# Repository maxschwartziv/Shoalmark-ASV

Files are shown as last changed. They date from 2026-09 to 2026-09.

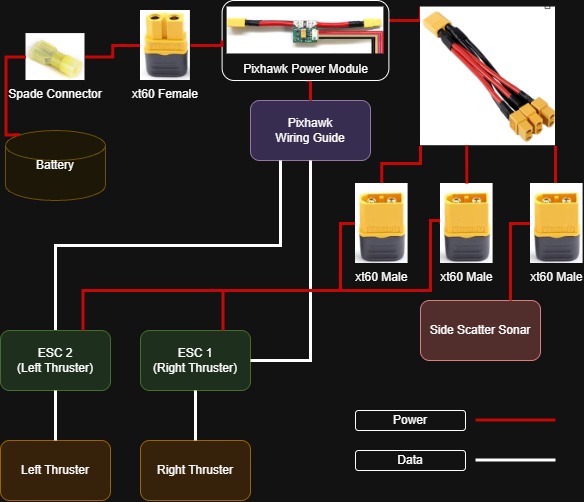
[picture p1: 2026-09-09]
Wiring Diagram Droneboat-Page-1.jpg

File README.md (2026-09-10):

**[3d print Instructions.pdf](https://github.com/user-attachments/files/32030344/3d.print.Instructions.pdf)**

pvc_ring_half_clamp 18x	

pvc_to_box_bracket 	4x

horizontal_to_vertical 1x

horizontal_to_vertical_receiver 6x

thruster_to_pvc	2x

**Parts can be printed 4 ways:**

On a creality machine with All_Parts.3mf

Place individual .3mf files

Generate/modify parts with openscad, connector_parts.scad

**[My website Build Page](https://www.droneboatfleet.com/shoalmark-asv)**

shoalmark3

shoalmark
shoalmark_thruster2

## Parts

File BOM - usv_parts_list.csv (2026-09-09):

Category | Item | Qty | Unit Price (USD) | Line Total (USD) | Source | Link | Notes
Sonar | Humminbird HELIX 7 CHIRP MEGA SI GPS G4 fish finder (transducer included) | 1 | 715 | 715 | Amazon | https://www.amazon.com/dp/B0CG6P1TD5 | ASIN B0CG6P1TD5; model 411930-1
Hull | Freein inflatable bodyboard, 40" x 21" x 4" | 1 | 80 | 80 | Amazon | https://www.amazon.com/dp/B0F1C778M2 | ASIN B0F1C778M2; hull/float platform
Frame | Charlotte Pipe 1/2" x 10 ft CPVC SDR11 pipe, plain end | 1 | 10 | 10 | Home Depot | https://www.homedepot.com/p/Charlotte-Pipe-1-2-In-X-10-Ft-CPVC-SDR11-Pipe-Plain-End-Corrosion-Resistant-for-Hot-and-Cold-Water-Distribution-CTS-12005-0600/100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 | 0.625 in OD / 0.485 in ID / 0.068 in wall
Frame | 1 in. x 2 in. x 8 ft. Furring Strip Board | 1 | 1 | 1 | Home Depot | https://www.homedepot.com/p/1-in-x-2-in-x-8-ft-Furring-Strip-Board-160954/100009348 | Actual Product Thickness (in.) 0.75 in,
Propulsion | APISQUEEN underwater thruster, CCW, 1.3 kg thrust | 1 | 65 | 65 | Amazon | https://www.amazon.com/dp/B0C74CMXR9?lv=shuf&channelId=500&plpRedirect=mhFallback&th=1 | ASIN B0C74CMXR9; 12-16V (3-4S), 8A max, 130W, 210 g
Propulsion | APISQUEEN underwater thruster, CW, 1.3 kg thrust | 1 | 65 | 65 | Amazon | https://www.amazon.com/dp/B0C74DFDYW | ASIN B0C74DFDYW; counter-rotating pair with above
Control | Pixhawk PX4 2.4.8 flight controller kit | 1 | 220 | 220 | Amazon | https://www.amazon.com/Controller-Wireless-Telemetry-Quadcopter-Multirotor/dp/B07NRMFTXL | ASIN B07NRMFTXL; incl. NEO-M8N GPS, 433 MHz telemetry pair, power module, PPM, mini OSD, safety switch, buzzer, I2C splitter
Control | HotRC transmitter + F-06A receiver set | 1 | 30 | 30 | Amazon | https://www.amazon.com/dp/B09Y8XT53X | ASIN B09Y8XT53X
Power | Akiisolo AK015 LiFePO4 battery, 12.8V 15Ah (192Wh) + charger | 1 | 40 | 40 | Amazon | https://www.amazon.com/dp/B0DLP6HWR5 | ASIN B0DLP6HWR5; 20A continuous / 30A peak
Power | XT60H connector pairs (male/female) | 1 | 12 | 12 | Amazon | https://www.amazon.com/dp/B0DPBP1N59 | ASIN B0DPBP1N59
Power | 2pcs XT60 Parallel Battery Connector Extension Y Splitter 3-Way (1Male to 3Female) | 1 | 10 | 10 | amazon | https://www.amazon.com/ATNSINC-Parallel-Connector-Extension-Splitter/dp/B0FWBMPTS4?s=industrial
Power | Duplex marine wire, 16 AWG / 2-conductor | 1 | 23 | 23 | Amazon | https://www.amazon.com/dp/B0FMK5YLB9 | ASIN B0FMK5YLB9; tinned copper, red/black
Enclosure | IP-rated enclosure with clear hinged lid | 1 | 70 | 70 | Amazon | https://www.amazon.com/dp/B09324TNT7 | ASIN B09324TNT7; electronics box
Enclosure | Cable glands / bulkhead cord grips, 6-pack | 1 | 10 | 10 | Amazon | https://www.amazon.com/dp/B0DKXHWSVX | ASIN B0DKXHWSVX; slotted, for pass-through wiring
Fasteners | Hanglife M4 heat-set threaded inserts, M4 x D6 x L6, 100 pcs | 1 | 10 | 10 | Amazon | https://www.amazon.com/dp/B0CS6XGMFD | ASIN B0CS6XGMFD; price read off the listing screenshot in the source doc
Fasteners | SVLING M4 x 12 mm socket cap screws, SS304 DIN 912, 200 pcs | 1 | 10 | 10 | Amazon | https://www.amazon.com/dp/B0GHNKNBMP | ASIN B0GHNKNBMP; includes hex key
Fasteners | TICONN 100 Pcs Nylon Spade Connector Kit, Insulated Crimp Wire Connectors | 1 | 10 | 10 | Amazon | https://www.amazon.com/TICONN-Disconnect-Connectors-Electrical-Assortment/dp/B08BZ972B5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
Adhesives & Sealing | GE Advanced Silicone 2 sealant, clear, window & door | 1 | 8 | 8 | Amazon | https://www.amazon.com/dp/B0C9VT9KD2 | ASIN B0C9VT9KD2; 100% waterproof, not paintable
Adhesives & Sealing | IXR Pro CA glue set (thin/medium/thick) + FX616 accelerator | 1 | 15 | 15 | Amazon | https://www.amazon.com/dp/B0D1DFSDMW | ASIN B0D1DFSDMW; 500 ml accelerator, applicator tips included
Ground Station | HOTWAV rugged Android 14 tablet | 1 | 209 | 209 | Amazon | https://www.amazon.com/dp/B0DK99XX8F | ASIN B0DK99XX8F; QGroundControl host
Ground Station | USB4 40 Gbps USB-C adapter | 1 | 10 | 10 | Amazon | https://www.amazon.com/dp/B0BN3LKKPQ | ASIN B0BN3LKKPQ
Printed Parts | PETG filament for printed parts (152.13 g / 49.80 m) | 1 | 4.56 | 4.56 | In-house |  | Cost, mass and 11h05m print time from the Creality slicer G-code preview in the source doc
Printed Parts | pvc_ring_half_clamp (printed) | 18 | 0 | 0 | In-house |  | connector_parts.scad; filament cost carried on the row above
Printed Parts | pvc_to_box_bracket (printed) | 4 | 0 | 0 | In-house |  | connector_parts.scad; filament cost carried above
Printed Parts | horizontal_to_vertical (printed) | 1 | 0 | 0 | In-house |  | connector_parts.scad; filament cost carried above
Printed Parts | horizontal_to_vertical_receiver (printed) | 6 | 0 | 0 | In-house |  | connector_parts.scad; filament cost carried above
Printed Parts | thruster_to_pvc (printed) | 2 | 0 | 0 | In-house |  | connector_parts.scad; filament cost carried above
 | GRAND TOTAL |  |  | 1627.56
SUBTOTALS BY CATEGORY
Sonar |  |  |  | 715
Hull |  |  |  | 80
Frame |  |  |  | 11
Propulsion |  |  |  | 130
Control |  |  |  | 250
Power |  |  |  | 85
Enclosure |  |  |  | 80
Fasteners |  |  |  | 30
Adhesives & Sealing |  |  |  | 23
Ground Station |  |  |  | 219
Printed Parts |  |  |  | 4.56

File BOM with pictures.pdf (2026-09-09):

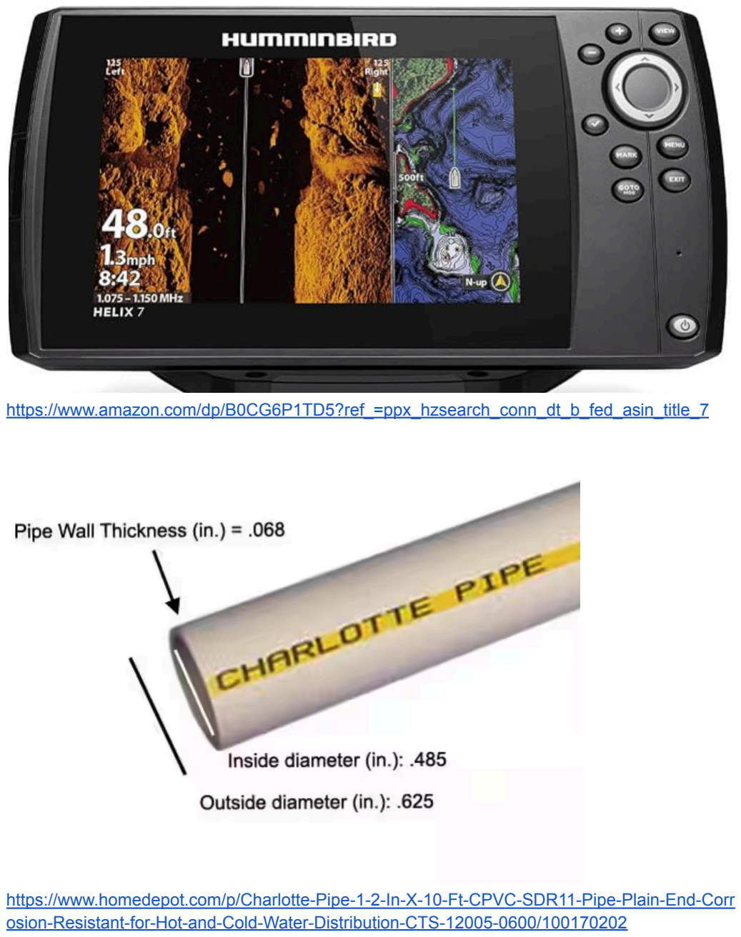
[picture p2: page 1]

https://www.amazon.com/dp/B0CG6P1TD5?ref_=ppx_hzsearch_conn_dt_b_fed_asin_title_7

https://www.homedepot.com/p/Charlotte-Pipe-1-2-In-X-10-Ft-CPVC-SDR11-Pipe-Plain-End-Corrosion-Resistant-for-Hot-and-Cold-Water-Distribution-CTS-12005-0600/100170202 (https://www.homedepot.com/p/Charlotte-Pipe-1-2-In-X-10-Ft-CPVC-SDR11-Pipe-Plain-End-Corrosion-Resistant-for-Hot-and-Cold-Water-Distribution-CTS-12005-0600/100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)

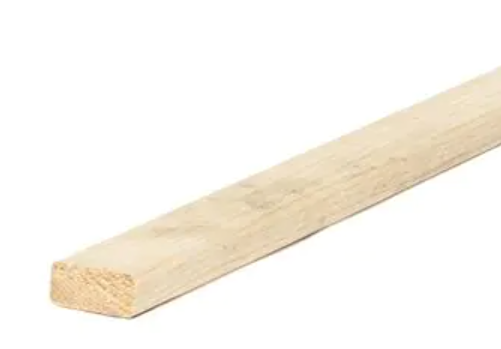
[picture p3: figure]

https://www.homedepot.com/p/1-in-x-2-in-x-8-ft-Furring-Strip-Board-160954/100009348

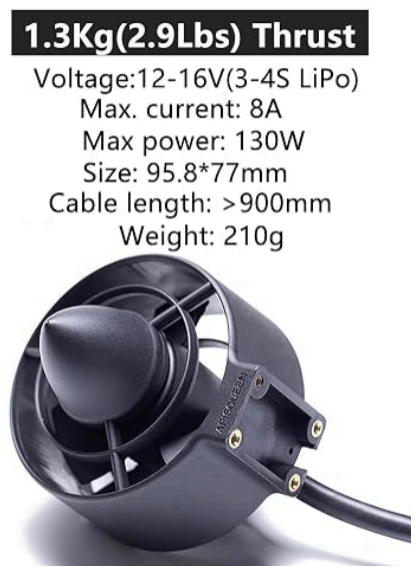
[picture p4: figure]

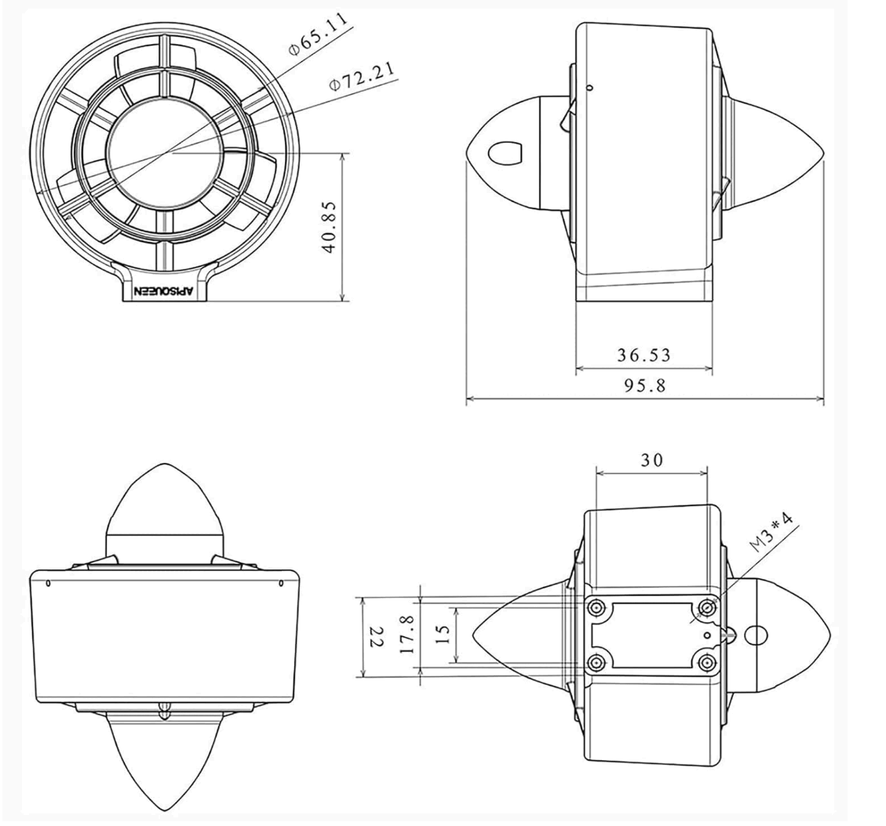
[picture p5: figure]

CCW
https://www.amazon.com/dp/B0C74CMXR9?ref_=ppx_hzsearch_conn_dt_b_fed_asin_title_2&th=1 (https://www.amazon.com/dp/B0C74CMXR9?ref_=ppx_hzsearch_conn_dt_b_fed_asin_title_2&th=1)

CW
https://www.amazon.com/dp/B0C74DFDYW?ref_=ppx_hzsearch_conn_dt_b_fed_asin_title_1&th=1 (https://www.amazon.com/dp/B0C74DFDYW?ref_=ppx_hzsearch_conn_dt_b_fed_asin_title_1&th=1)

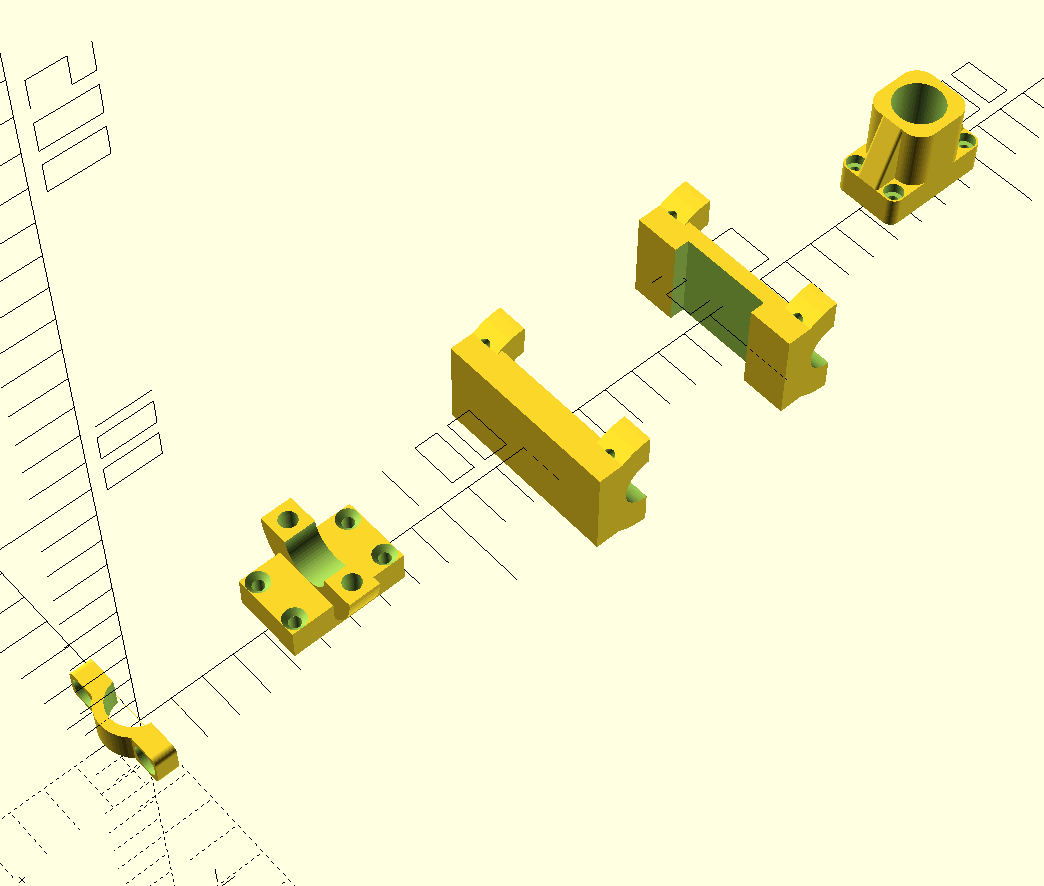
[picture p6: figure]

Connector_parts.scad

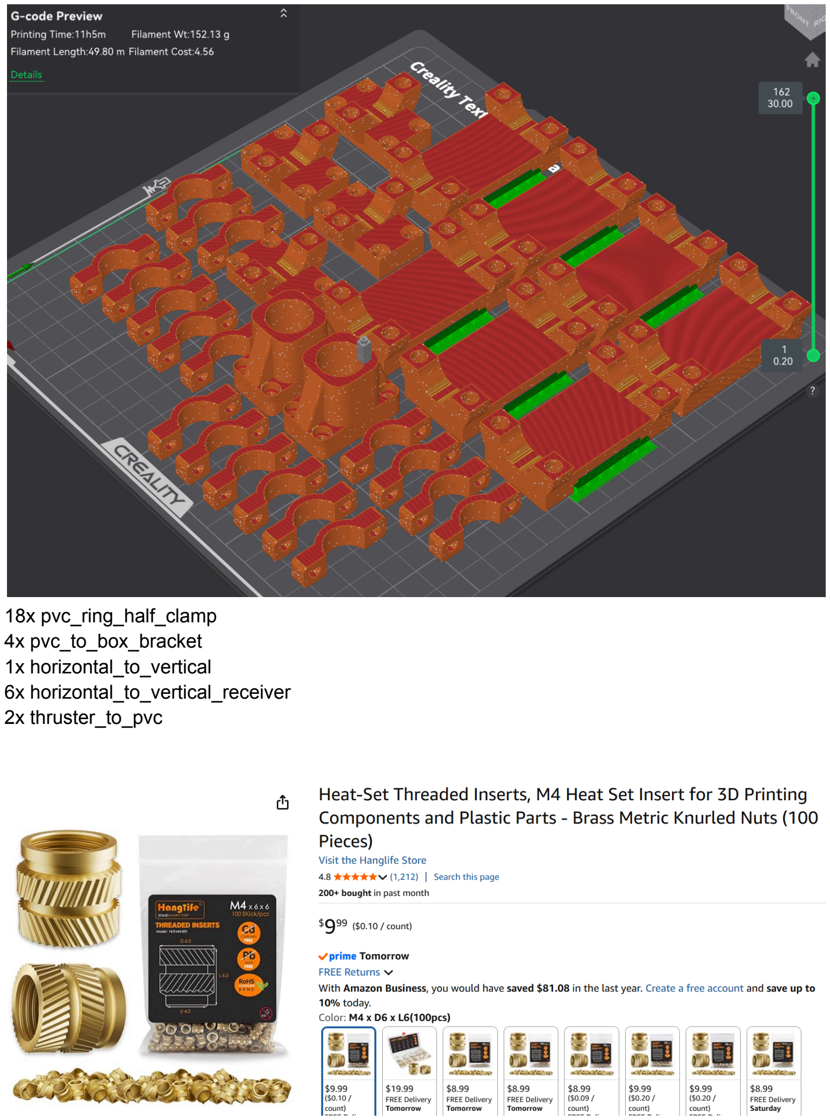
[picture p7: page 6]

18x pvc_ring_half_clamp
4x pvc_to_box_bracket
1x horizontal_to_vertical
6x horizontal_to_vertical_receiver 2x thruster_to_pvc https://www.amazon.com/dp/B0CS6XGMFD?ref_=ppx_hzsearch_conn_dt_b_fed_asin_title_1&th=1 (https://www.amazon.com/dp/B0CS6XGMFD?ref_=ppx_hzsearch_conn_dt_b_fed_asin_title_1&th=1)

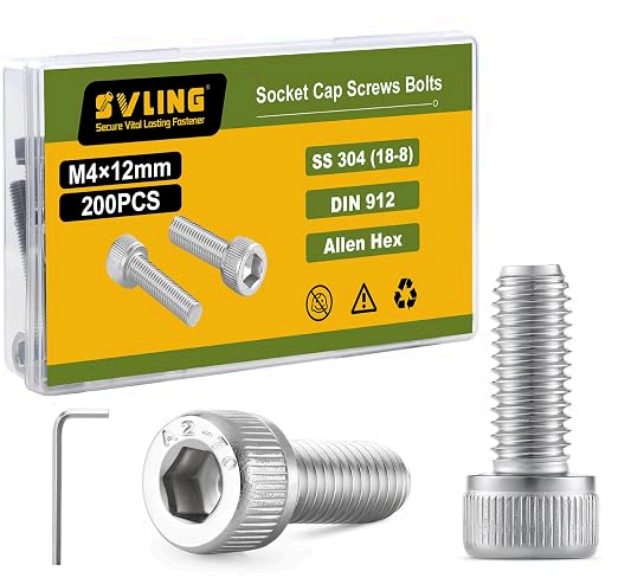
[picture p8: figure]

https://www.amazon.com/dp/B0GHNKNBMP?ref_=ppx_hzsearch_conn_dt_b_fed_asin_title_2&th=1 (https://www.amazon.com/dp/B0GHNKNBMP?ref_=ppx_hzsearch_conn_dt_b_fed_asin_title_2&th=1)

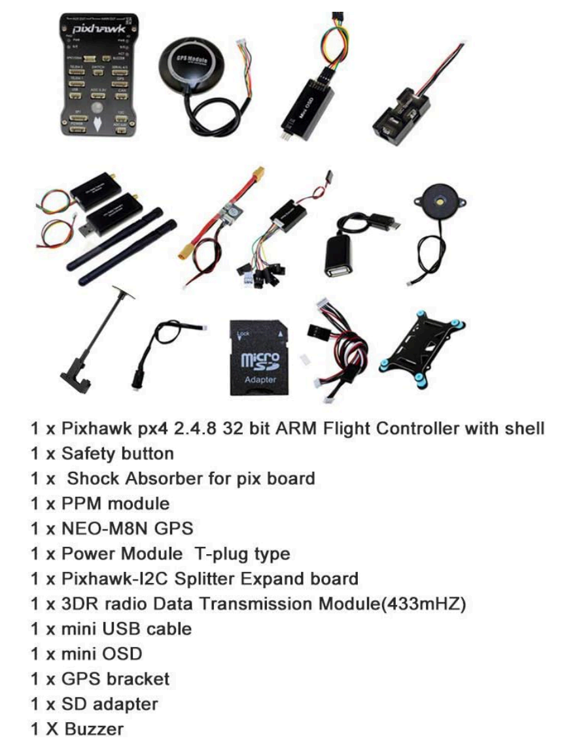
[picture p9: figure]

https://www.amazon.com/Controller-Wireless-Telemetry-Quadcopter-Multirotor/dp/B07NRMFTXL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 (https://www.amazon.com/Controller-Wireless-Telemetry-Quadcopter-Multirotor/dp/B07NRMFTXL)


https://www.amazon.com/dp/B09Y8XT53X?ref_=ppx_hzsearch_conn_dt_b_fed_asin_title_5&th=1 (https://www.amazon.com/dp/B09Y8XT53X?ref_=ppx_hzsearch_conn_dt_b_fed_asin_title_5&th=1)


https://www.amazon.com/dp/B0DPBP1N59?ref_=ppx_hzsearch_conn_dt_b_fed_asin_title_2


https://www.amazon.com/ATNSINC-Parallel-Connector-Extension-Splitter/dp/B0FWBMPTS4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 2CMUmj-yIz3onAg68kl-kQaaRciO1NKCPf9Ao1064QUwiFAuhfjtw.Za56zgOVwaETWVL4tyUzh M8Izj1yVeNUsYodQw8dfpM&dib_tag=se&keywords=xt60%2Bsplitter&qid=1788024247&s=indu strial&sprefix=xt60%2Bsplitter%2Cindustrial%2C223&sr=1-18&th=1 (https://www.amazon.com/ATNSINC-Parallel-Connector-Extension-Splitter/dp/B0FWBMPTS4?s=industrial)


https://www.amazon.com/dp/B08BZ972B5?ref_=ppx_hzsearch_conn_dt_b_fed_asin_title_4&th=1 (https://www.amazon.com/dp/B08BZ972B5?ref_=ppx_hzsearch_conn_dt_b_fed_asin_title_4&th=1)


https://www.amazon.com/dp/B0FMK5YLB9?ref=ppx_yo2ov_dt_b_fed_asin_title&th=1


https://www.amazon.com/dp/B0DLP6HWR5?ref_=ppx_hzsearch_conn_dt_b_fed_asin_title_14&th=1 (https://www.amazon.com/dp/B0DLP6HWR5?ref_=ppx_hzsearch_conn_dt_b_fed_asin_title_14&th=1)


https://www.amazon.com/dp/B09324TNT7?ref_=ppx_hzsearch_conn_dt_b_fed_asin_title_5&th=1 (https://www.amazon.com/dp/B09324TNT7?ref_=ppx_hzsearch_conn_dt_b_fed_asin_title_5&th=1)


https://www.amazon.com/dp/B0DKXHWSVX?ref_=ppx_hzsearch_conn_dt_b_fed_asin_title_3&th=1 (https://www.amazon.com/dp/B0DKXHWSVX?ref_=ppx_hzsearch_conn_dt_b_fed_asin_title_3&th=1)


https://www.amazon.com/dp/B0C9VT9KD2?ref_=ppx_hzsearch_conn_dt_b_fed_asin_title_1&th=1 (https://www.amazon.com/dp/B0C9VT9KD2?ref_=ppx_hzsearch_conn_dt_b_fed_asin_title_1&th=1)


https://www.amazon.com/dp/B0D1DFSDMW?ref_=ppx_hzsearch_conn_dt_b_fed_asin_title_1&th=1 (https://www.amazon.com/dp/B0D1DFSDMW?ref_=ppx_hzsearch_conn_dt_b_fed_asin_title_1&th=1)


https://www.amazon.com/dp/B0F1C778M2?ref_=ppx_hzsearch_conn_dt_b_fed_asin_title_1&th=1 (https://www.amazon.com/dp/B0F1C778M2?ref_=ppx_hzsearch_conn_dt_b_fed_asin_title_1&th=1)


https://www.amazon.com/dp/B0DK99XX8F?ref_=ppx_hzsearch_conn_dt_b_fed_asin_title_1&th=1 (https://www.amazon.com/dp/B0DK99XX8F?ref_=ppx_hzsearch_conn_dt_b_fed_asin_title_1&th=1)

https://www.amazon.com/dp/B0BN3LKKPQ?ref_=ppx_hzsearch_conn_dt_b_fed_asin_title_1&th=1 (https://www.amazon.com/dp/B0BN3LKKPQ?ref_=ppx_hzsearch_conn_dt_b_fed_asin_title_1&th=1)

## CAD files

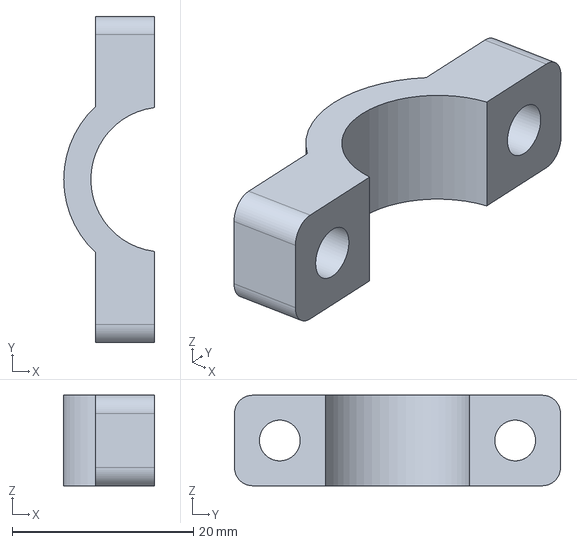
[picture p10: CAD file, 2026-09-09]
ring_0.5inID_soloSplit10mmWidth.FCStd
10.0 x 36.0 x 10.0 mm

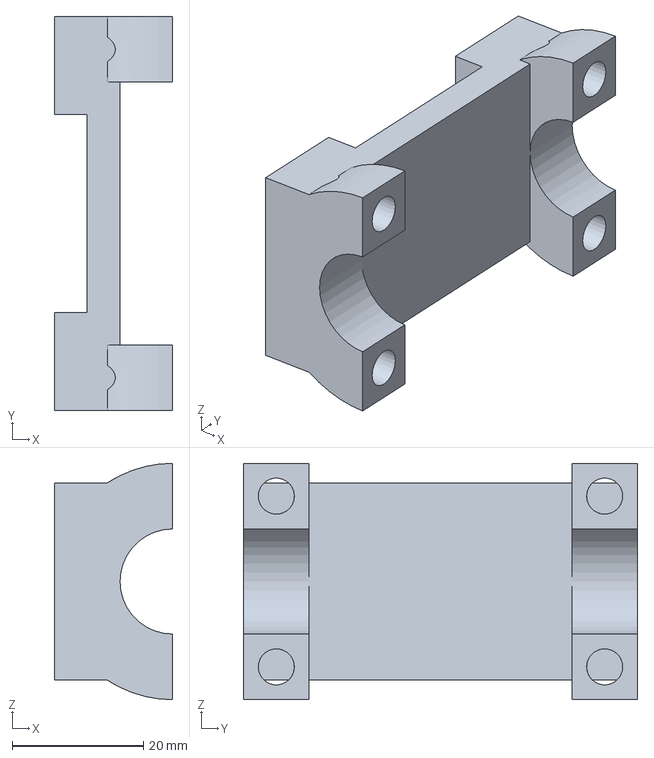
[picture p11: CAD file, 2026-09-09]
horizonalToVerticalReceiver-Body.3mf
18.0 x 60.0 x 36.0 mm

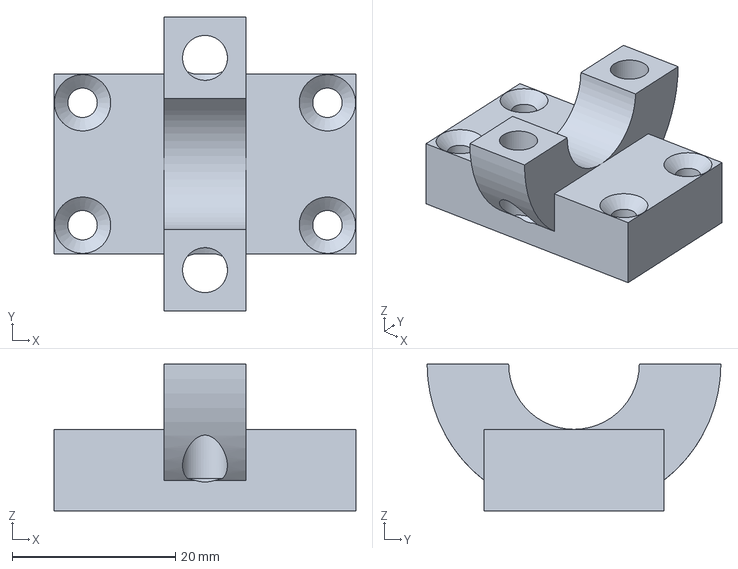
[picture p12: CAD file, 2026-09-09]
16mmPVCtoBox.FCStd
37.0 x 36.0 x 18.0 mm

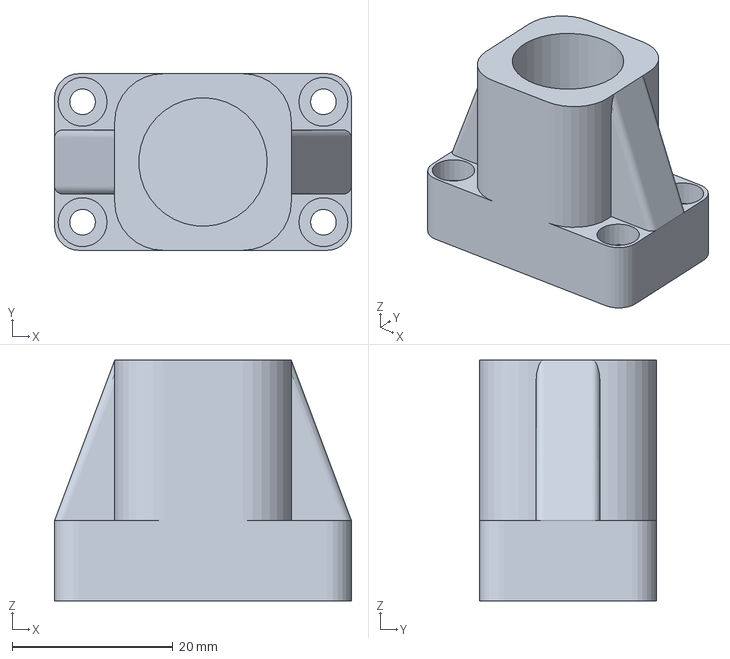
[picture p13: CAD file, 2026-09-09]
thrusterTo16mmPVC-Body.3mf
37.0 x 22.0 x 30.0 mm

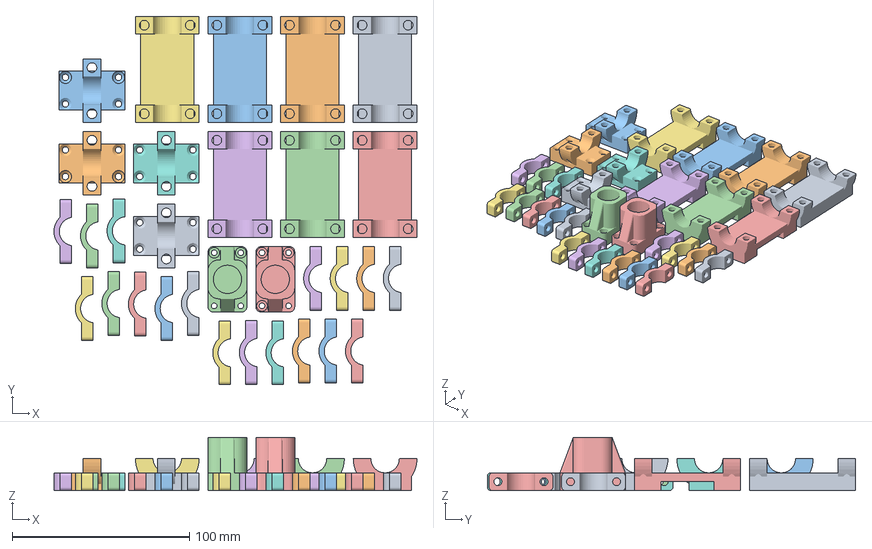
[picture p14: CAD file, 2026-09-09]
All_Parts.3mf
205.0 x 208.0 x 30.0 mm

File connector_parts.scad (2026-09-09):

// ============================================================================
// connector_parts.scad
//
// Parametric OpenSCAD library for the five FreeCAD connector bodies in the
// parent folder. Every part is a module whose arguments default to the
// dimensions of the original FCStd, so calling it with no arguments reproduces
// the original solid.
//
//   part module                            FreeCAD source
//   -----------------------------------    ---------------------------------
//   pvc_ring_half_clamp()                  ring_0.5inID_soloSplit10mmWidth
//   pvc_to_box_bracket()                   16mmPVCtoBox
//   horizontal_to_vertical()               horizonalToVertical
//   horizontal_to_vertical_receiver()      horizonalToVerticalReceiver
//   thruster_to_pvc()                      thrusterTo16mmPVC
//
// USAGE
//   use <connector_parts.scad>             // modules only, nothing rendered
//   pvc_to_box_bracket(socket_bore = 20, socket_od = 40);
//
//   Opening this file directly (or include-ing it) renders the part named by
//   the `part` variable below, which also drives the Customizer.
//
// Each part keeps the origin and orientation of its FreeCAD body, so an export
// can be overlaid on the original to compare.
//
// Arguments left as undef are derived from the others; the derivation is noted
// at each one and matches the constraint used in the original sketch.
// ============================================================================

/* [Part] */
// Which part to render when this file is opened directly.
part = "all"; // [pvc_ring_half_clamp, pvc_to_box_bracket, horizontal_to_vertical, horizontal_to_vertical_receiver, thruster_to_pvc, all]

// ---------------------------------------------------------------------------
// Hole sizes, exposed for the Customizer and the direct-open front end.
// These feed cp_part() below; the part modules themselves take the same values
// as arguments, so a `use <>` caller can ignore all of this and pass its own.
// Every other dimension stays at the module default - see the part modules for
// the full argument list.
// ---------------------------------------------------------------------------

/* [Holes: ring half clamp] */
ring_pipe_od           = 16;    // bore the pair of halves closes onto
ring_bolt_hole_d       = 4.5;   // bolt through hole
ring_counterbore_d     = 8.3;   // socket-head recess
ring_counterbore_depth = 3.5;   // in from the outer face of the ear

/* [Holes: PVC to box bracket] */
box_socket_bore       = 16;     // pipe OD the cradle takes
box_mount_hole_d      = 3.6;    // plate bolt through hole
box_mount_csk_d       = 6.9;    // countersink top diameter
box_mount_csk_angle   = 90;     // countersink included angle
box_side_hole_d       = 5.5;    // screw down through the cradle wall
box_side_hole_depth   = 14;
box_drill_point_angle = 118;    // 0 for a flat bottom

/* [Holes: horizontal to vertical pair] */
h2v_socket_bore = 16;           // pipe OD each cradle takes
h2v_hole_d      = 5.5;
h2v_hole_depth  = 10;           // 8 reproduces the usable depth of the FCStd

/* [Holes: thruster adapter] */
thr_socket_bore    = 16;        // pipe OD the riser is bored for
thr_socket_depth   = 20;        // bore depth down from the top of the riser
thr_mount_hole_d   = 3.2;       // plate bolt through hole
thr_mount_cb_d     = 6.1;       // socket-head recess
thr_mount_cb_depth = 3.4;

/* [Quality] */
$fn = $preview ? 64 : 160;

/* [Hidden] */
CP_EPS = 0.01;
CP_BIG = 400;

// ---------------------------------------------------------------------------
// Customizer / direct-open front end
// ---------------------------------------------------------------------------
if (part == "all") {
    translate([  0,   0, 0]) cp_part("pvc_ring_half_clamp");
    translate([ 60,   0, 0]) cp_part("pvc_to_box_bracket");
    translate([130,   0, 0]) cp_part("horizontal_to_vertical");
    translate([200,   0, 0]) cp_part("horizontal_to_vertical_receiver");
    translate([280,   0, 0]) cp_part("thruster_to_pvc");
} else cp_part(part);

// One named part, built with the hole sizes set above.
module cp_part(name) {
    if (name == "pvc_ring_half_clamp")
        pvc_ring_half_clamp(
            pipe_od           = ring_pipe_od,
            bolt_hole_d       = ring_bolt_hole_d,
            counterbore_d     = ring_counterbore_d,
            counterbore_depth = ring_counterbore_depth);

    else if (name == "pvc_to_box_bracket")
        pvc_to_box_bracket(
            socket_bore       = box_socket_bore,
            mount_hole_d      = box_mount_hole_d,
            mount_csk_d       = box_mount_csk_d,
            mount_csk_angle   = box_mount_csk_angle,
            side_hole_d       = box_side_hole_d,
            side_hole_depth   = box_side_hole_depth,
            drill_point_angle = box_drill_point_angle);

    else if (name == "horizontal_to_vertical")
        horizontal_to_vertical(
            socket_bore = h2v_socket_bore,
            hole_d      = h2v_hole_d,
            hole_depth  = h2v_hole_depth);

    else if (name == "horizontal_to_vertical_receiver")
        horizontal_to_vertical_receiver(
            socket_bore = h2v_socket_bore,
            hole_d      = h2v_hole_d,
            hole_depth  = h2v_hole_depth);

    else if (name == "thruster_to_pvc")
        thruster_to_pvc(
            socket_bore    = thr_socket_bore,
            socket_depth   = thr_socket_depth,
            mount_hole_d   = thr_mount_hole_d,
            mount_cb_d     = thr_mount_cb_d,
            mount_cb_depth = thr_mount_cb_depth);

    else echo(str("connector_parts: unknown part name '", name, "'"));
}

// ===========================================================================
// SHARED HELPERS
// ===========================================================================

// Through hole with a countersink cut into the top face of a slab that runs
// from z = 0 to z = thickness. Centred on the current origin.
module cp_countersunk_hole(hole_d, csk_d, csk_angle, thickness) {
    csk_depth = (csk_d - hole_d) / 2 / tan(csk_angle / 2);
    translate([0, 0, -CP_EPS]) cylinder(h = thickness + 2 * CP_EPS, d = hole_d);
    translate([0, 0, thickness - csk_depth])
        cylinder(h  = csk_depth + CP_EPS,
                 d1 = hole_d,
                 d2 = csk_d + 2 * CP_EPS * tan(csk_angle / 2));
}

// Through hole with a flat-bottomed counterbore cut into the top face of a slab
// that runs from z = 0 to z = thickness.
module cp_counterbored_hole(hole_d, cb_d, cb_depth, thickness) {
    translate([0, 0, -CP_EPS]) cylinder(h = thickness + 2 * CP_EPS, d = hole_d);
    translate([0, 0, thickness - cb_depth])
        cylinder(h = cb_depth + CP_EPS, d = cb_d);
}

// Hole drilled straight down from z = 0, `depth` deep, with an optional conical
// drill point below the flat bottom. point_angle = 0 gives a flat bottom.
module cp_drilled_hole(d, depth, point_angle = 0) {
    translate([0, 0, -depth]) cylinder(h = depth + CP_EPS, d = d);
    if (point_angle > 0) {
        pt = (d / 2) / tan(point_angle / 2);
        translate([0, 0, -depth - pt]) cylinder(h = pt, d1 = 0, d2 = d);
    }
}

// Open half-socket ("cradle") for a pipe. Canonical placement: axis along +Y
// from y = 0 to y = len, bore centred on the origin, and everything at x > 0
// removed so the cradle opens towards +X.
module cp_cradle(bore, od, len) {
    intersection() {
        rotate([-90, 0, 0])
            difference() {
                cylinder(h = len, d = od);
                translate([0, 0, -CP_EPS]) cylinder(h = len + 2 * CP_EPS, d = bore);
            }
        translate([-CP_BIG, -CP_BIG, -CP_BIG / 2])
            cube([CP_BIG, 2 * CP_BIG, CP_BIG]);
    }
}

// A 2D profile drawn in the XZ plane, extruded through `thk` in Y about y = 0.
module cp_xz_prism(thk) {
    translate([0, thk / 2, 0]) rotate([90, 0, 0]) linear_extrude(thk) children();
}
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

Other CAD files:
horizonalToVertical.FCStd
horizonalToVerticalReceiver.FCStd
ring_0.5inID_soloSplit10mmWidth_v2.3mf
horizonalToVertical-Body.3mf
thrusterTo16mmPVC.FCStd
16mmPVCtoBox.3mf
